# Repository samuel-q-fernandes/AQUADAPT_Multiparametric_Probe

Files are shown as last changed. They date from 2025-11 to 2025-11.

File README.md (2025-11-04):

# Development of a Cost-Effective Multiparametric Probe for Continuous, Real-Time Monitoring of Aquatic Environments

**AQUADAPT | AQUA-V1** is an open-source platform for in-situ water-quality/quantity monitoring (**pH, electrical conductivity (EC), temperature, and water level**). The system targets robust, long-term field deployments with an emphasis on reproducibility, traceability, and low total cost.

The hardware integrates an **ESP32** controller (LILYGO® T-Call with **SIM800L**) for data acquisition and processing, plus **GSM/GPRS** telemetry, **microSD** logging, and **solar power** support (MPPT + Li-ion). Firmware duty-cycles sensing and transmission, then enters **deep sleep** between cycles to minimize average power consumption, enabling multi-day autonomy and continuous operation under normal sunlight.

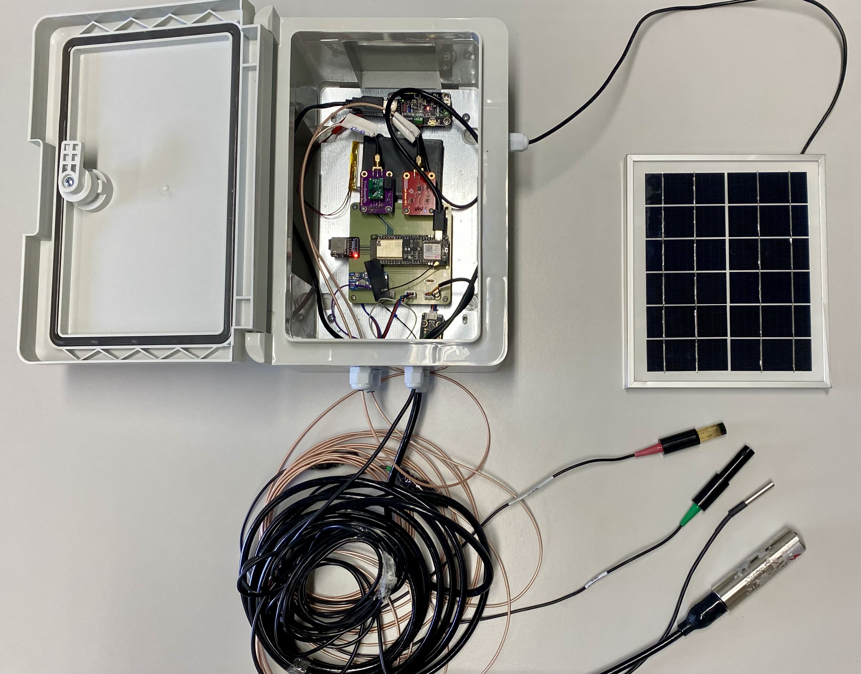
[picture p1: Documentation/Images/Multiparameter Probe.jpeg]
Multiparameter probe overview


This repository provides the full stack: **KiCad** design files, **Arduino/C++** firmware, a **PHP API** for authenticated data ingest, the **SQL schema** to bootstrap the database, and a **web dashboard** for data visualization. Documentation includes wiring, configuration, deployment notes, and server setup.

To support transparent metrology, the docs also detail the complete measurement workflow and a **GUM-conforming uncertainty budget** (expanded uncertainties reported at *k* = 2), making results auditable across deployments. A link to the peer-reviewed manuscript will be added here upon acceptance.

Software is released under the **MIT License** (see `LICENSE`). 
**A link to the peer-reviewed manuscript will be added here upon acceptance by the journal.**

## Bill of Materials (BOM)

*A summarized BOM based on the components described in the manuscript. 

> **Target cost:** sub-€1,000 (sensor/probe choices and enclosure options drive most of the variation).

| Subsystem | Item / Model | Qty | Notes |
|---|---|---:|---|
| **MCU, comms & logging** | **LILYGO® TTGO T-Call v1.4** (ESP32 + SIM800L) | 1 | ESP32 controller with integrated GSM/GPRS modem; UART to modem, SPI to microSD. |
|  | **microSD module + 16 GB microSD card** | 1 | On-device redundant logging (CSV/JSON). |
| **Analog / digital interfaces** | **EZO™ Isolator / isolated carrier (pH)** | 1 | Electrical isolation to reduce ground/EMI coupling into pH front-end. |
|  | **EZO™ Conductivity (EC) Circuit** | 1 | Digital EC interface (I²C/UART); temperature aware as configured. |
|  | **MT3608 DC–DC boost converter** | 1 | Boost supply (e.g., 5 V → 12–36 V) for the level/pressure sensor. |
| **Sensors** | **Mini Lab-grade pH probe (ENV-20-pH)** | 1 | Glass electrode; used with Nernst temperature compensation. |
|  | **Mini Conductivity probe K = 1.0 (ENV-20-EC-K1.0)** | 1 | EC probe; three-point calibration via cell constant. |
|  | **DS18B20 temperature sensor** | 1 | 12-bit (0.0625 °C); OneWire; **4.7 kΩ** pull-up to Vcc. |
|  | **Industrial submersible pressure/level sensor (0–5 m)** | 1 | Analog output; hydrostatic level; powered via MT3608 boost. |
| **Custom PCB** | **Main carrier PCB (≈100 × 100 mm)** | 1 | Breakouts and headers for pH/EC/level/DS18B20, modem, power rails, and microSD. |
| **Power** | **PV panel (≈6 V / 5 W)** | 1 | Solar charging for autonomous operation. |
|  | **MPPT charge/power manager (≈900 mA charge)** | 1 | Manages PV → Li-ion charging and system power. |
|  | **Li-ion battery (3.7 V, ~4000 mAh)** | 1 | Energy storage; supports multi-day duty cycle. |
| **Cabling & enclosure** | **IP-rated enclosure with cable glands** | 1 | Houses electronics; strain relief and desiccant recommended. |
|  | **Sensor cable harness (~7 m)** | 2 | Extends probes from housing to water column. |
| **Passives** | **4.7 kΩ resistor** | 1 | DS18B20 pull-up. |
|  | **Sense resistor ~120 Ω (level channel)** | 1 | Per level/pressure readout design. |
| **Calibration materials** | **pH buffers (e.g., pH 4, 7, 9, 10; traceable)** | set | Used for multi-point pH calibration at measurement temperature. |
|  | **EC standards (e.g., 1413, 12 880, 80 000 µS/cm)** | set | Used to estimate cell constant and verify linearity. |

### Sourcing and integration notes
- **Region & connectivity:** confirm 2G/GPRS availability; if unavailable, substitute LTE-M/NB-IoT modem with matching firmware and power profile.  
- **Power budget:** size PV and battery for sampling + telemetry duty cycle and local insolation; include winter/cloud margins.  
- **EMI & grounding:** keep high-impedance pH paths short and away from digital lines; consider shielded cables and star-grounding.  
- **Calibration traceability:** document buffer/standard lot numbers, temperatures, and dates; store calibration IDs in firmware/config.

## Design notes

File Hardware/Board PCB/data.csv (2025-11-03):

Date | Temperature (°C) | Level (m) | Battery (bit) | Battery (%) | pH | Conductivity (uS/cm)
2023-02-27T12:04:39 | 18.00 | 64.59 | 5030 | 100.00 | 7.55 | 272.70
2023-02-27T12:05:02 | 18.00 | 63.93 | 5030 | 100.00 | 7.55 | 272.90
2023-02-27T12:05:34 | 18.00 | 57.30 | 5028 | 100.00 | 7.55 | 274.00
2023-02-27T12:08:57 | 18.06 | 58.46 | 5042 | 100.00 | 7.56 | 275.40
2023-02-27T12:09:22 | 18.12 | 52.79 | 5024 | 100.00 | 7.60 | 275.80
2023-02-27T12:11:48 | 18.12 | 65.50 | 5024 | 100.00 | 7.58 | 274.80
2023-02-27T12:14:06 | 18.19 | 55.31 | 5024 | 100.00 | 7.61 | 276.60
2023-02-27T12:16:24 | 18.31 | 54.86 | 5030 | 100.00 | 7.56 | 277.30
2023-02-27T12:18:41 | 18.37 | 57.76 | 5024 | 100.00 | 7.57 | 276.20
2023-02-27T12:20:57 | 18.44 | 66.08 | 5022 | 100.00 | 7.57 | 278.60
2023-02-27T12:23:26 | 18.56 | 65.46 | 5024 | 100.00 | 7.13 | 190.90

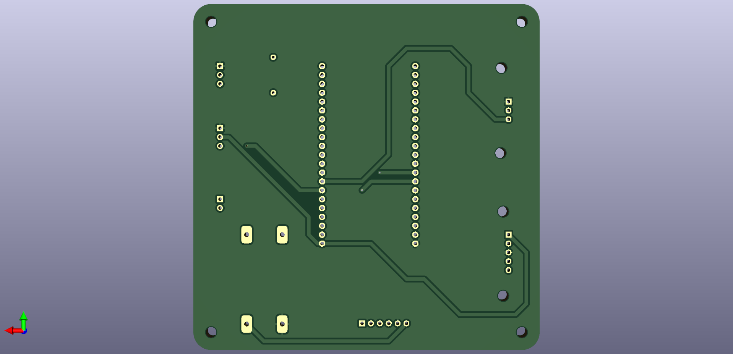
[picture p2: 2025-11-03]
Hardware/Board PCB/Board V1.0_bottom.png

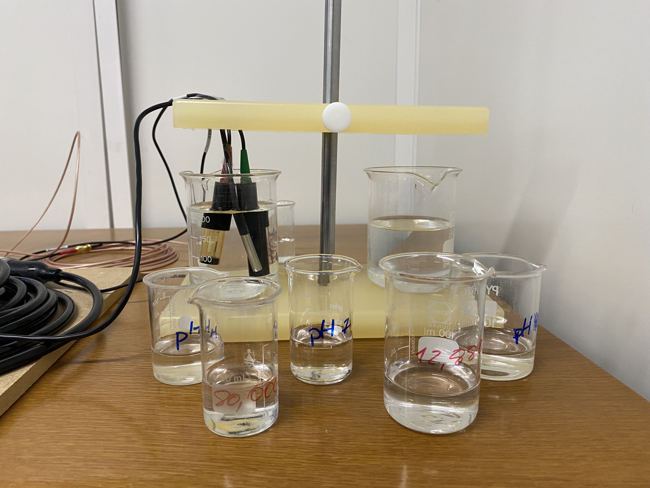
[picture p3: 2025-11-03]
Hardware/Board PCB/Sensores.jpeg

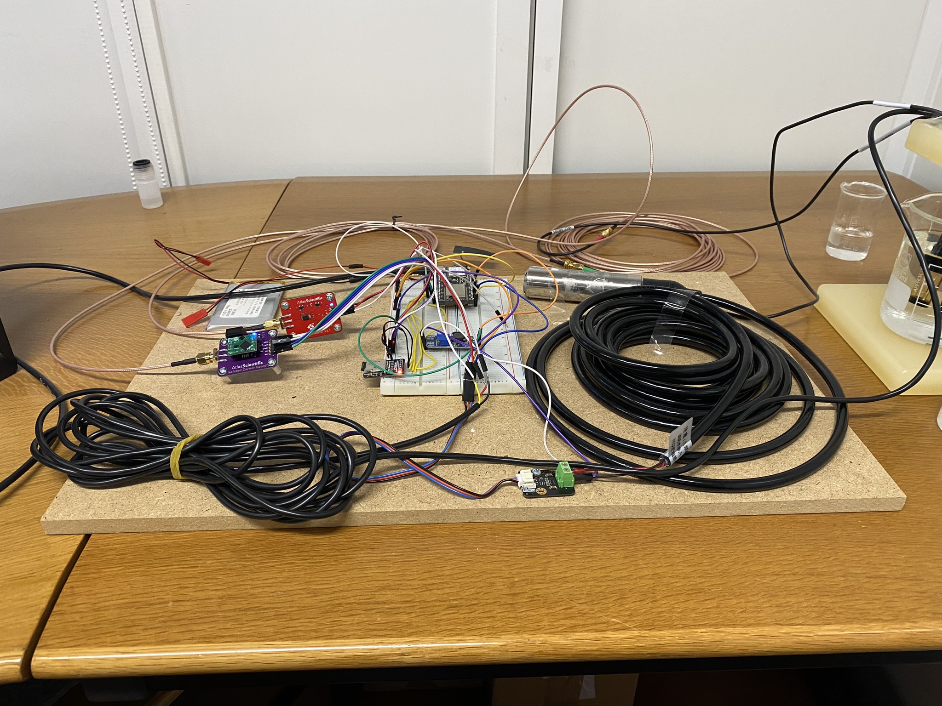
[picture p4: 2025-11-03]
Hardware/Board PCB/Sonda MP_.jpeg

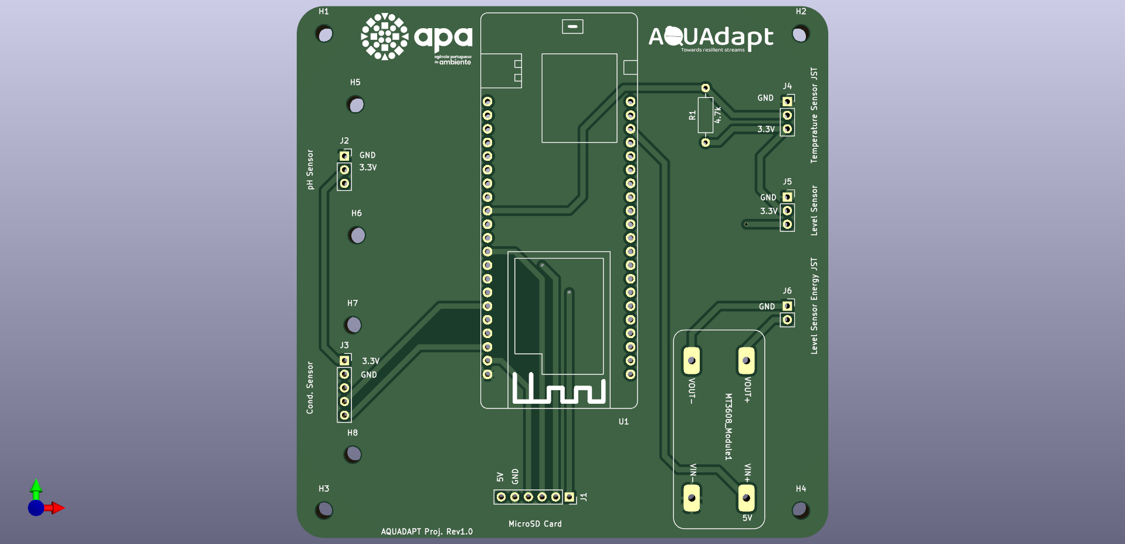
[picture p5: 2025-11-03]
Hardware/Board PCB/Board V1.0/Board V1.0_front.png

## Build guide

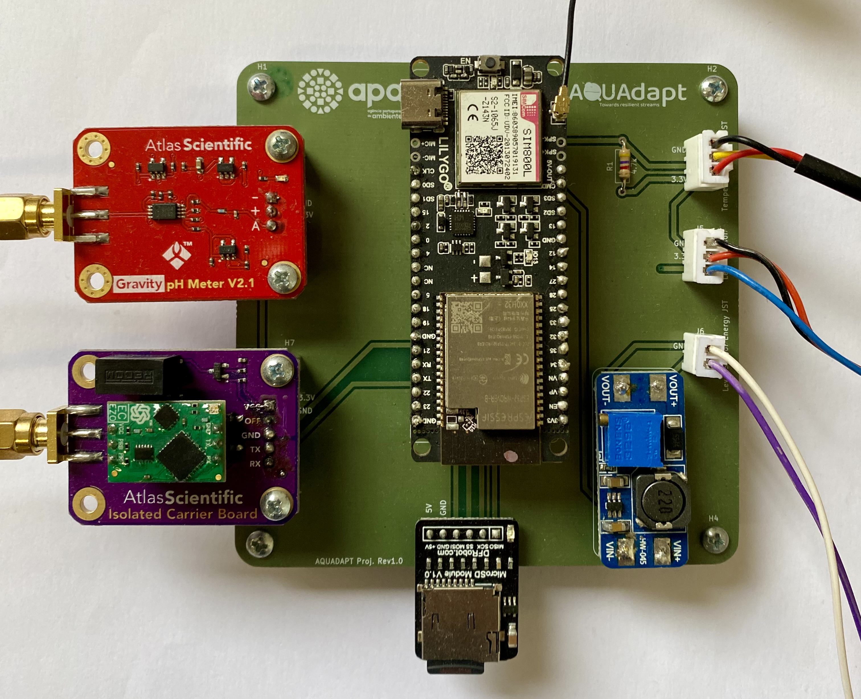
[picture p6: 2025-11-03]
Documentation/Images/Board Assembled 2.jpeg

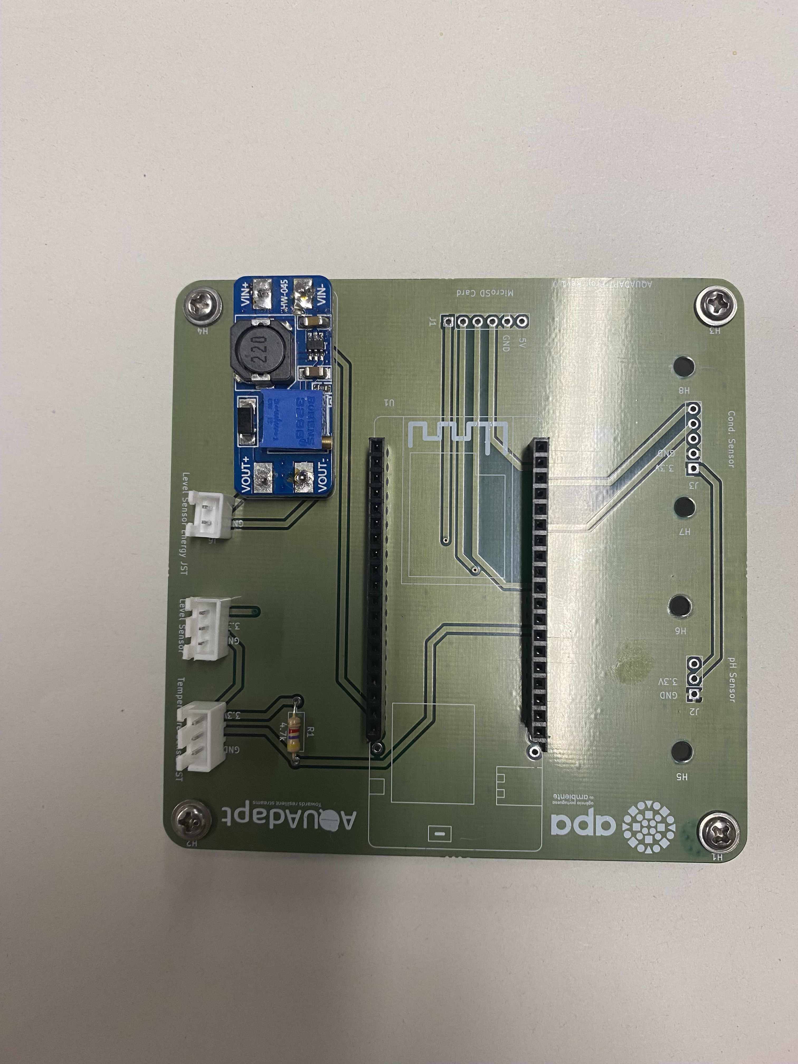
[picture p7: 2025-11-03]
Documentation/Images/Board Proto Step Up.jpeg

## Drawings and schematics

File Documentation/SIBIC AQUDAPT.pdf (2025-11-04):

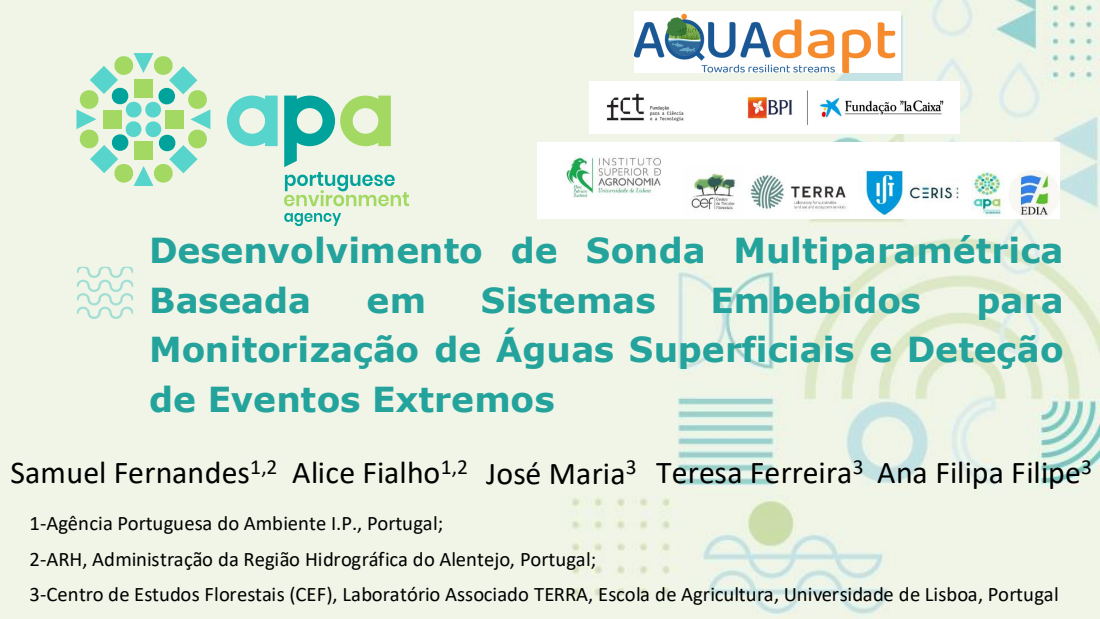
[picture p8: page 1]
Baseada; Sistemas; Embebidos; para; Samuel Fernandes¹,2 Alice Fialho¹,2; Teresa Ferreira³ Ana Filipa Filipe³; José Maria³

Desenvolvimento de Sonda Multiparamétrica
Monitorização de Águas Superficiais e Deteção
de Eventos Extremos

1-Agência Portuguesa do Ambiente I.P., Portugal;
2-ARH, Administração da Região Hidrográfica do Alentejo, Portugal;
3-Centro de Estudos Florestais (CEF), Laboratório Associado TERRA, Escola de Agricultura, Universidade de Lisboa, Portugal

## CONTENTS

## 1. Introdução

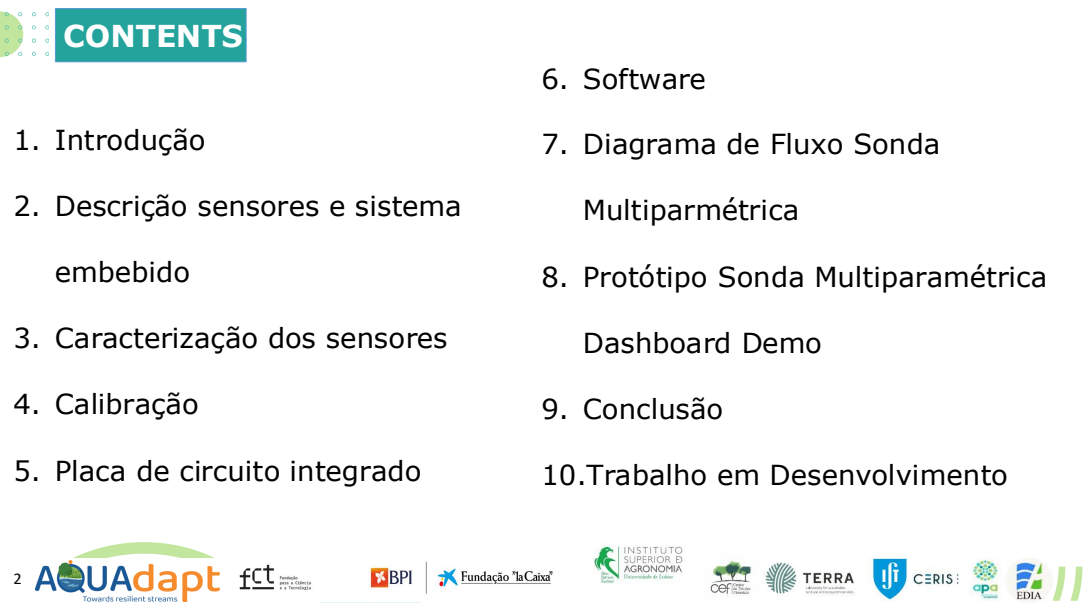
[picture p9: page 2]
embebido; 4. Calibração; 6. Software; Multiparmétrica; Dashboard Demo; 9. Conclusão

7. Diagrama de Fluxo Sonda

2. Descrição sensores e sistema

8. Protótipo Sonda Multiparamétrica

3. Caracterização dos sensores

5. Placa de circuito integrado

10.Trabalho em Desenvolvimento

## 1. Introdução

## A monitorização contínua em tempo real dos parâmetros de quantidade e qualidade da

## água é essencial para a deteção de eventos de poluição, tomada de decisão e gestão

eficaz de recursos naturais.

## Tradicionalmente a avaliação da qualidade da água é realizada por meio de amostragem direta e em laboratórios

## Não permite monitorização contínua nem observação de tendências sazonais

## Exigem custos significativos e podem estar sujeitas a potenciais degradações das amostras, erros de transcrição e atrasos temporais

## 1. Introdução

## O principal objetivo deste estudo é desenvolver uma sonda multiparamétrica com envio de dados remoto para a avaliação da qualidade e quantidade da água, visando melhorar a

precisão dos dados e apoiar a tomada de decisões na gestão de recursos hídricos.

## Os objetivos específicos são:

## - Determinar a incerteza associada aos sensores de pH, nível de água e

## condutividade

## - Realizar uma calibração dos sensores de pH, condutividade e nível de água

## - Projetar e desenvolver uma placa de circuito impresso para a integração dos

## componentes

## 2. Sensor pH

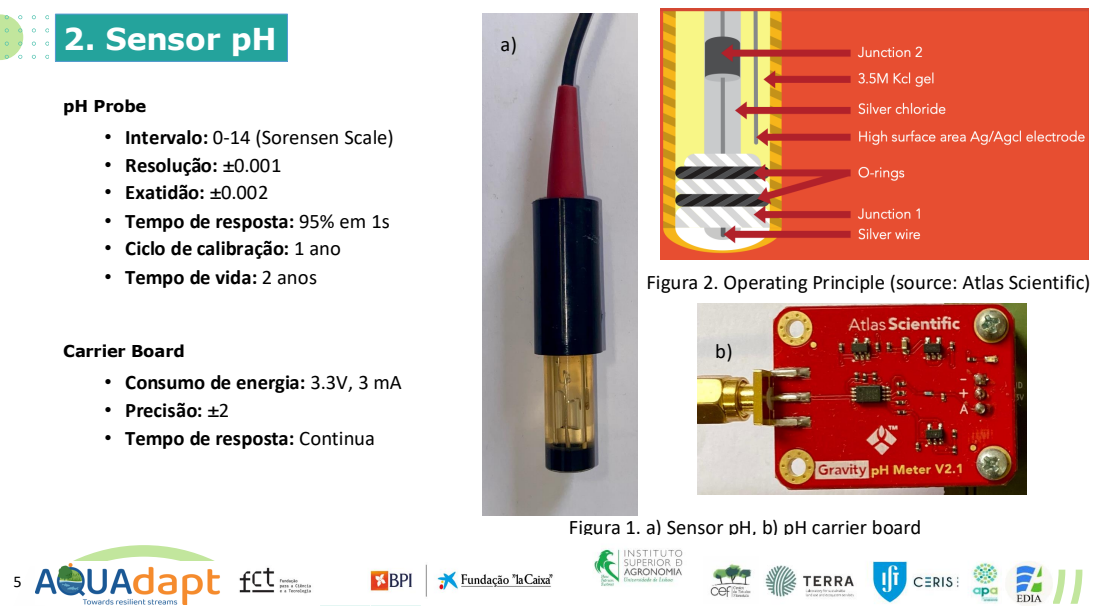
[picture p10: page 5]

pH Probe
• Intervalo: 0-14 (Sorensen Scale)
• Resolução: ±0.001
• Exatidão: ±0.002
• Tempo de resposta: 95% em 1s
• Ciclo de calibração: 1 ano
• Tempo de vida: 2 anos

Figura 2. Operating Principle (source: Atlas Scientific)

Carrier Board
• Consumo de energia: 3.3V, 3 mA
• Precisão: ±2
• Tempo de resposta: Continua

Figura 1. a) Sensor pH, b) pH carrier board

## 2. Sensor Condutividade

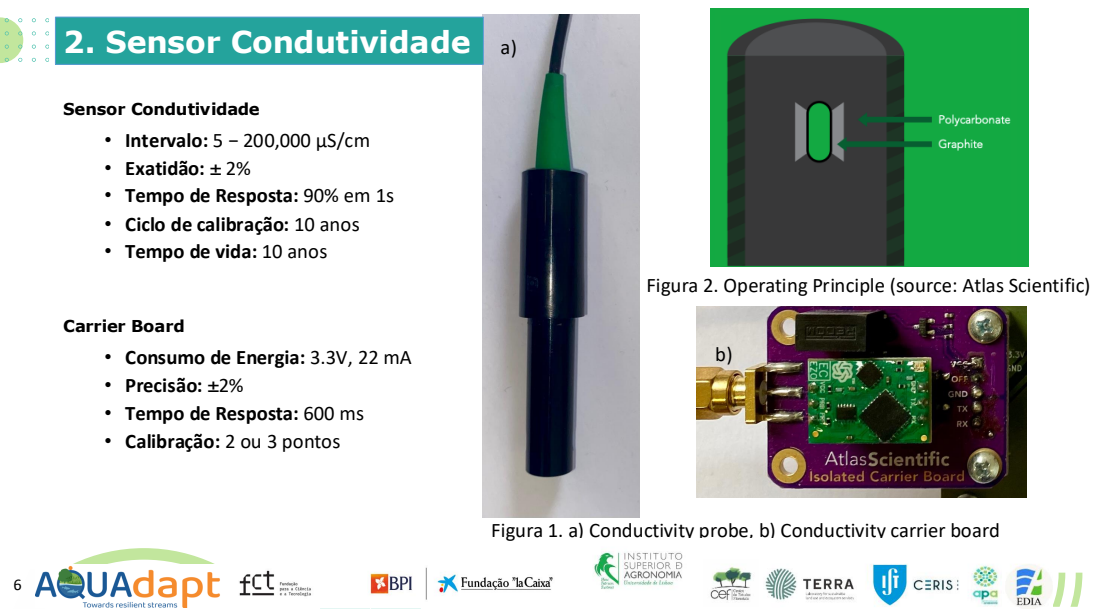
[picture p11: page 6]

Sensor Condutividade
• Intervalo: 5 − 200,000 μS/cm
• Exatidão: ± 2%
• Tempo de Resposta: 90% em 1s
• Ciclo de calibração: 10 anos
• Tempo de vida: 10 anos

Figura 2. Operating Principle (source: Atlas Scientific)

Carrier Board
• Consumo de Energia: 3.3V, 22 mA
• Precisão: ±2%
• Tempo de Resposta: 600 ms
• Calibração: 2 ou 3 pontos

Figura 1. a) Conductivity probe, b) Conductivity carrier board

## 2. Water Level Sensor

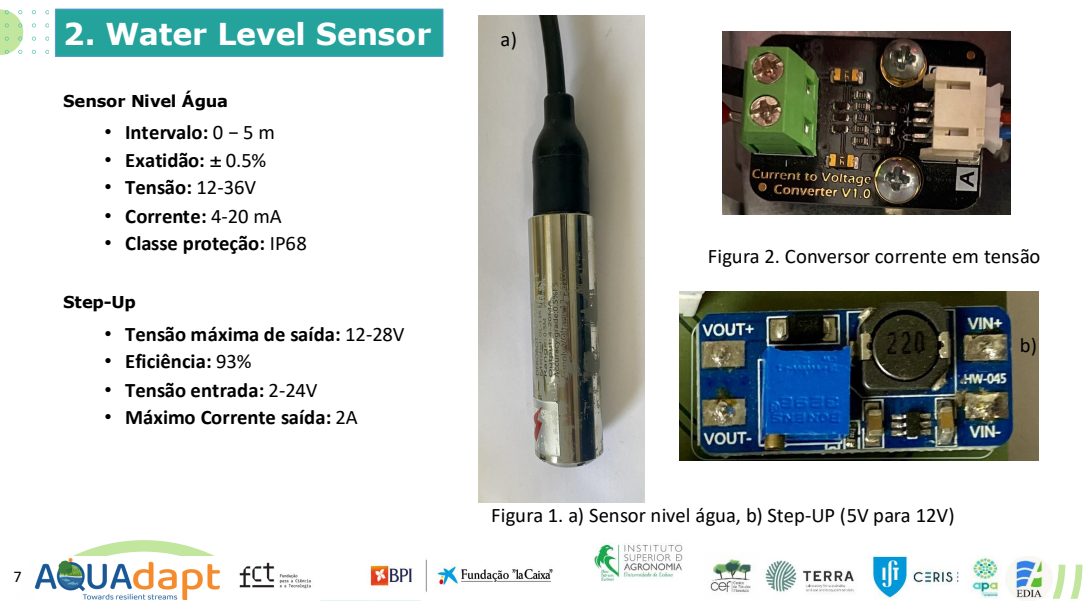
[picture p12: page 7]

Sensor Nivel Água
• Intervalo: 0 − 5 m
• Exatidão: ± 0.5%
• Tensão: 12-36V
• Corrente: 4-20 mA
• Classe proteção: IP68

Figura 2. Conversor corrente em tensão

Step-Up
• Tensão máxima de saída: 12-28V
• Eficiência: 93%
• Tensão entrada: 2-24V
• Máximo Corrente saída: 2A

Figura 1. a) Sensor nivel água, b) Step-UP (5V para 12V)

## 2. Temperature Sensor

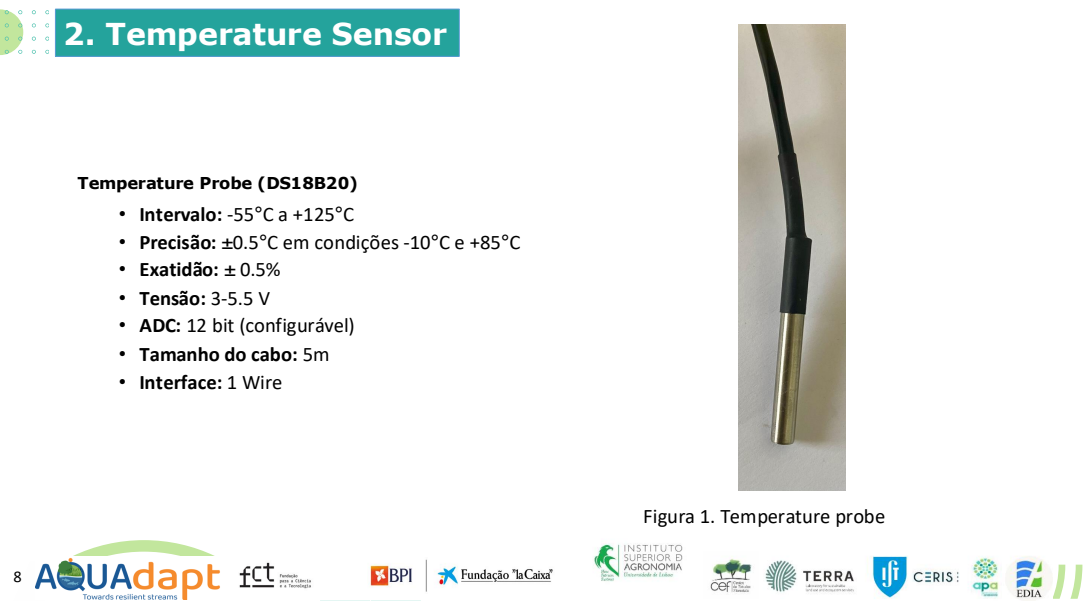
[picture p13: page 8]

Temperature Probe (DS18B20)
• Intervalo: -55°C a +125°C
• Precisão: ±0.5°C em condições -10°C e +85°C
• Exatidão: ± 0.5%
• Tensão: 3-5.5 V
• ADC: 12 bit (configurável)
• Tamanho do cabo: 5m
• Interface: 1 Wire

Figura 1. Temperature probe

## 2. Sistema Embebido

Lilygo SIM800L T-Call V1.4

- Microcontrolador baseado em um ESP32 (módulo WROVER, processador dual-core de 240 MHz)
- Possui um módulo SIM800L GSM/GPRS integrado para comunicação de longa distância
- Apresenta uma conexão para cartão nano SIM
- Integra uma funcionalidade de deep-sleep, que permite colocar a placa em modo de baixo consumo de energia entre as medições
- Tensão: 5V DC (via USB-C) of 3.3V DC (via 3V3 pin)
- ADC: Two ACD channels with 12 bit resolution
- Protocolos de Comunicação: SPI, I2C, CAN, and LIN, and UART
- Memória Flash: 4MB
- GPIO tensão: 3.3V*

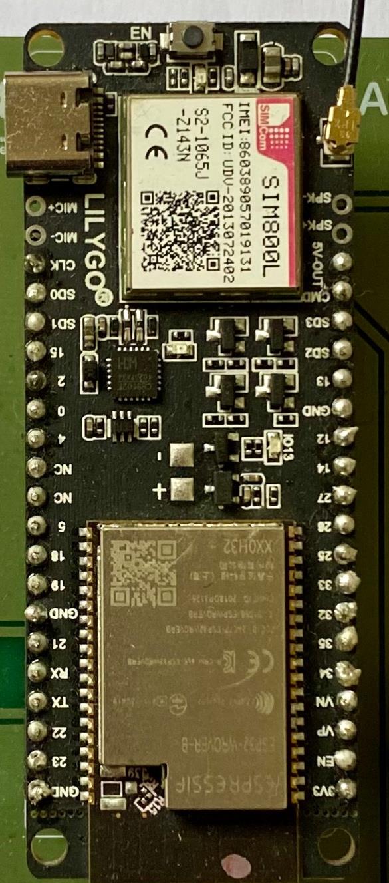
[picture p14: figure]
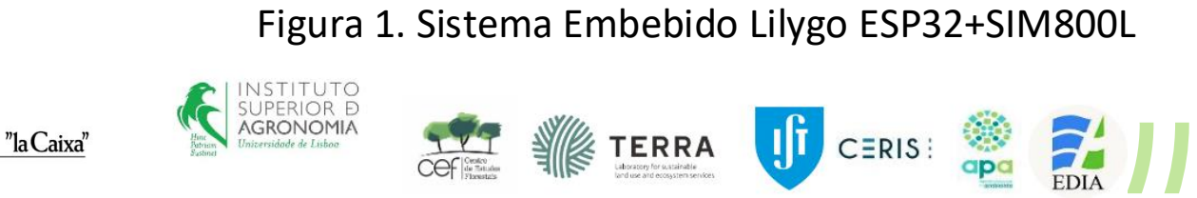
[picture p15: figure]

Figura 1. Sistema Embebido Lilygo ESP32+SIM800L
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

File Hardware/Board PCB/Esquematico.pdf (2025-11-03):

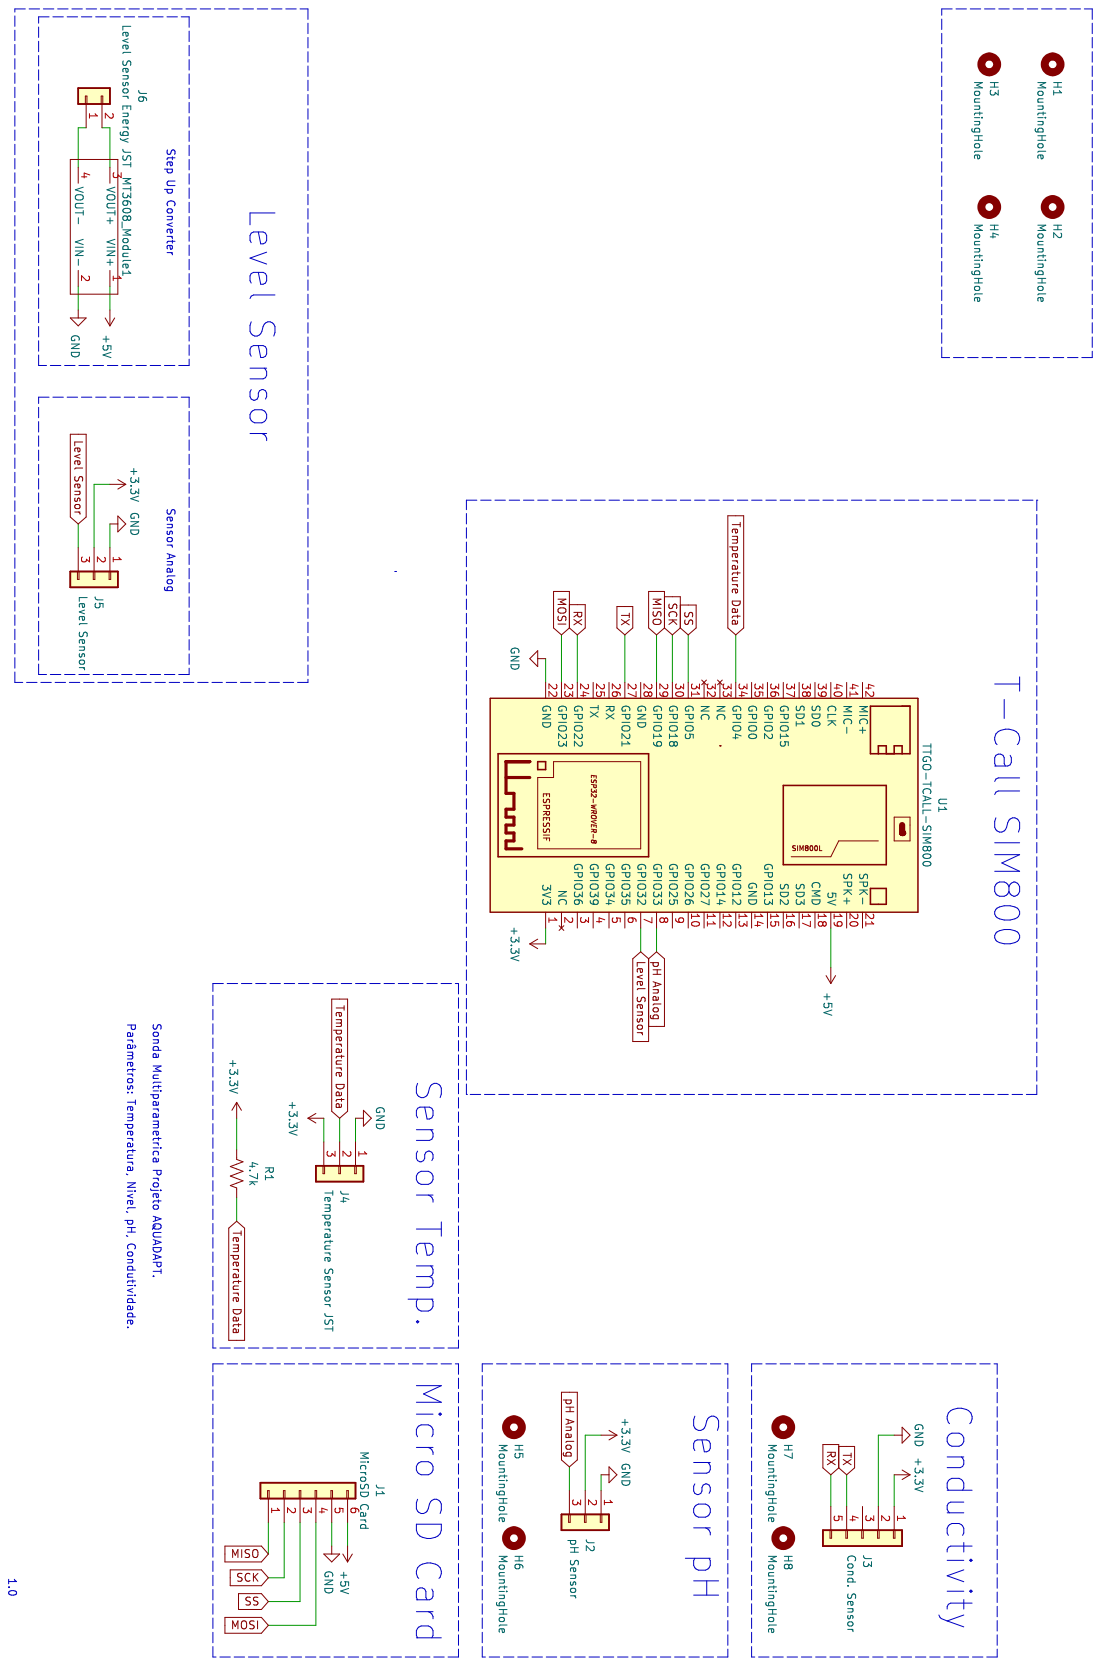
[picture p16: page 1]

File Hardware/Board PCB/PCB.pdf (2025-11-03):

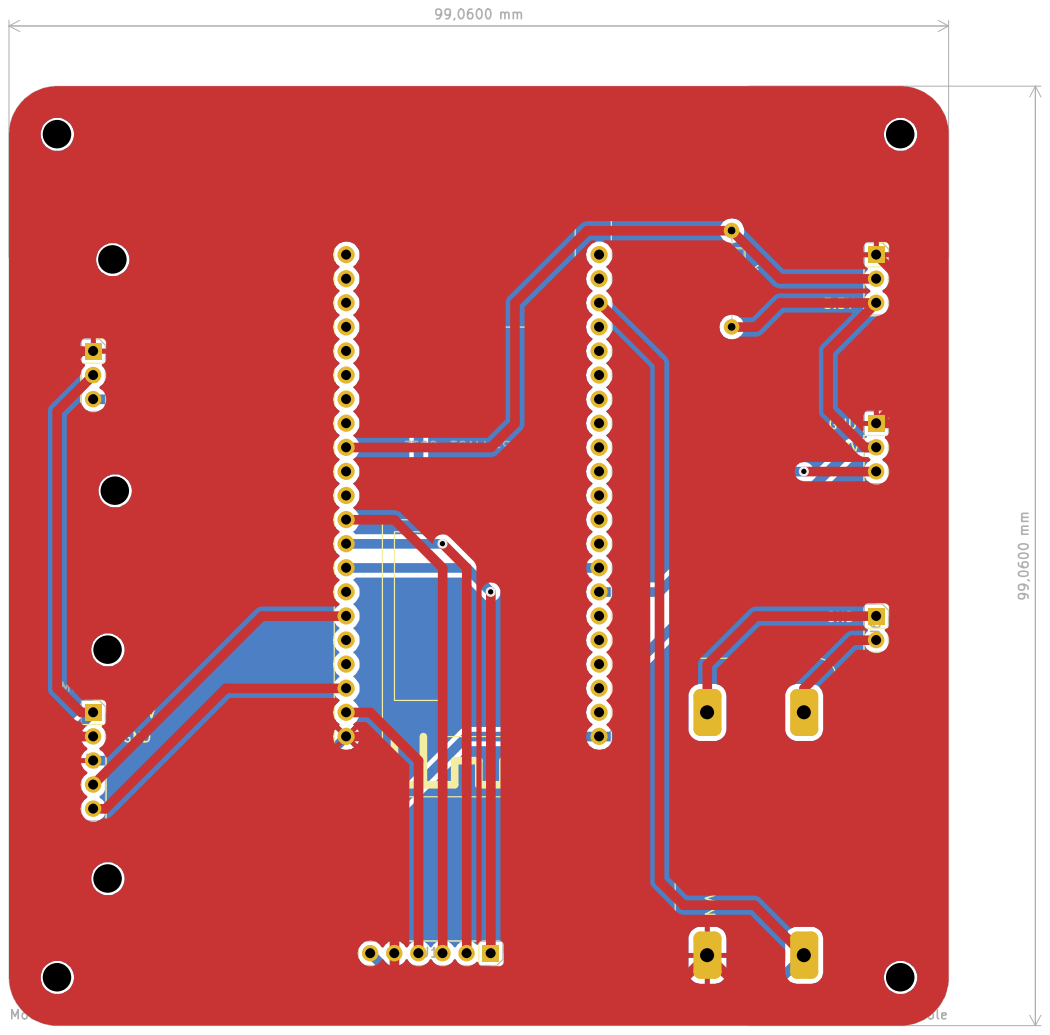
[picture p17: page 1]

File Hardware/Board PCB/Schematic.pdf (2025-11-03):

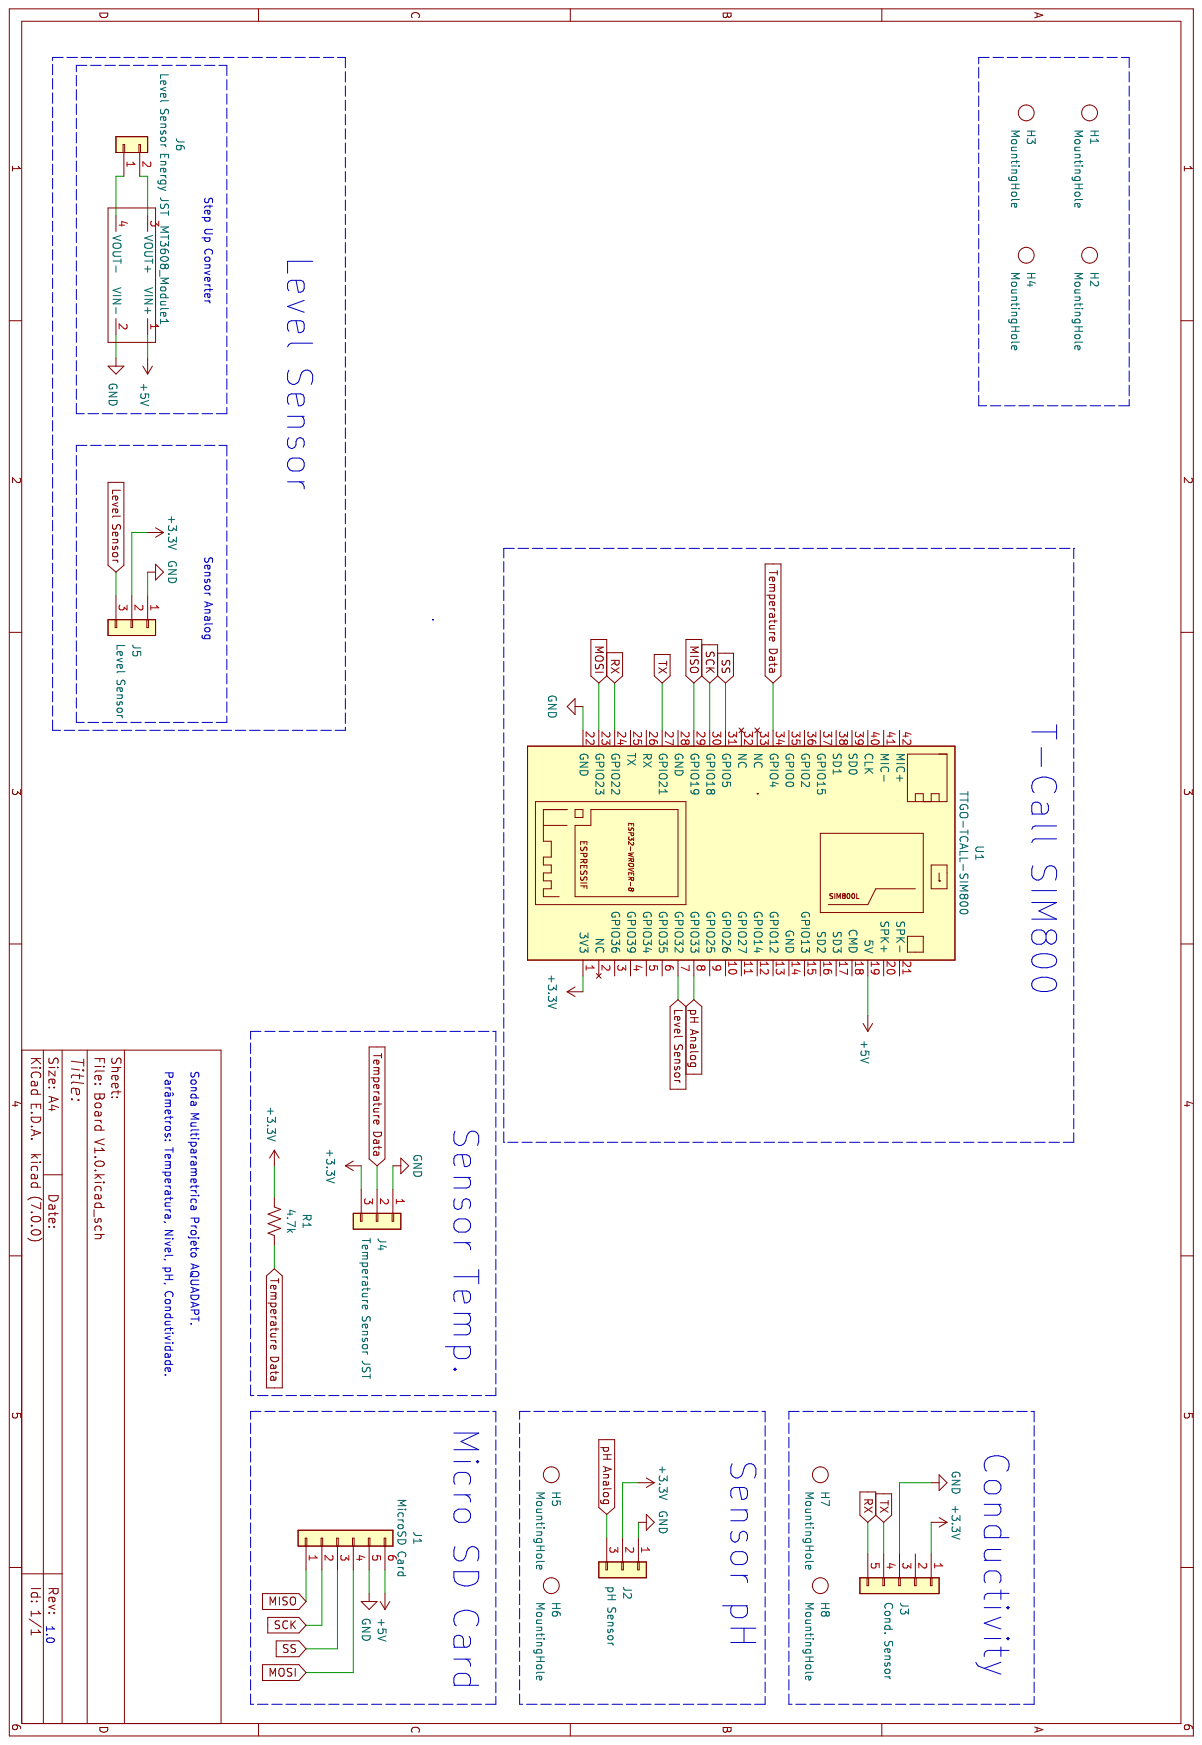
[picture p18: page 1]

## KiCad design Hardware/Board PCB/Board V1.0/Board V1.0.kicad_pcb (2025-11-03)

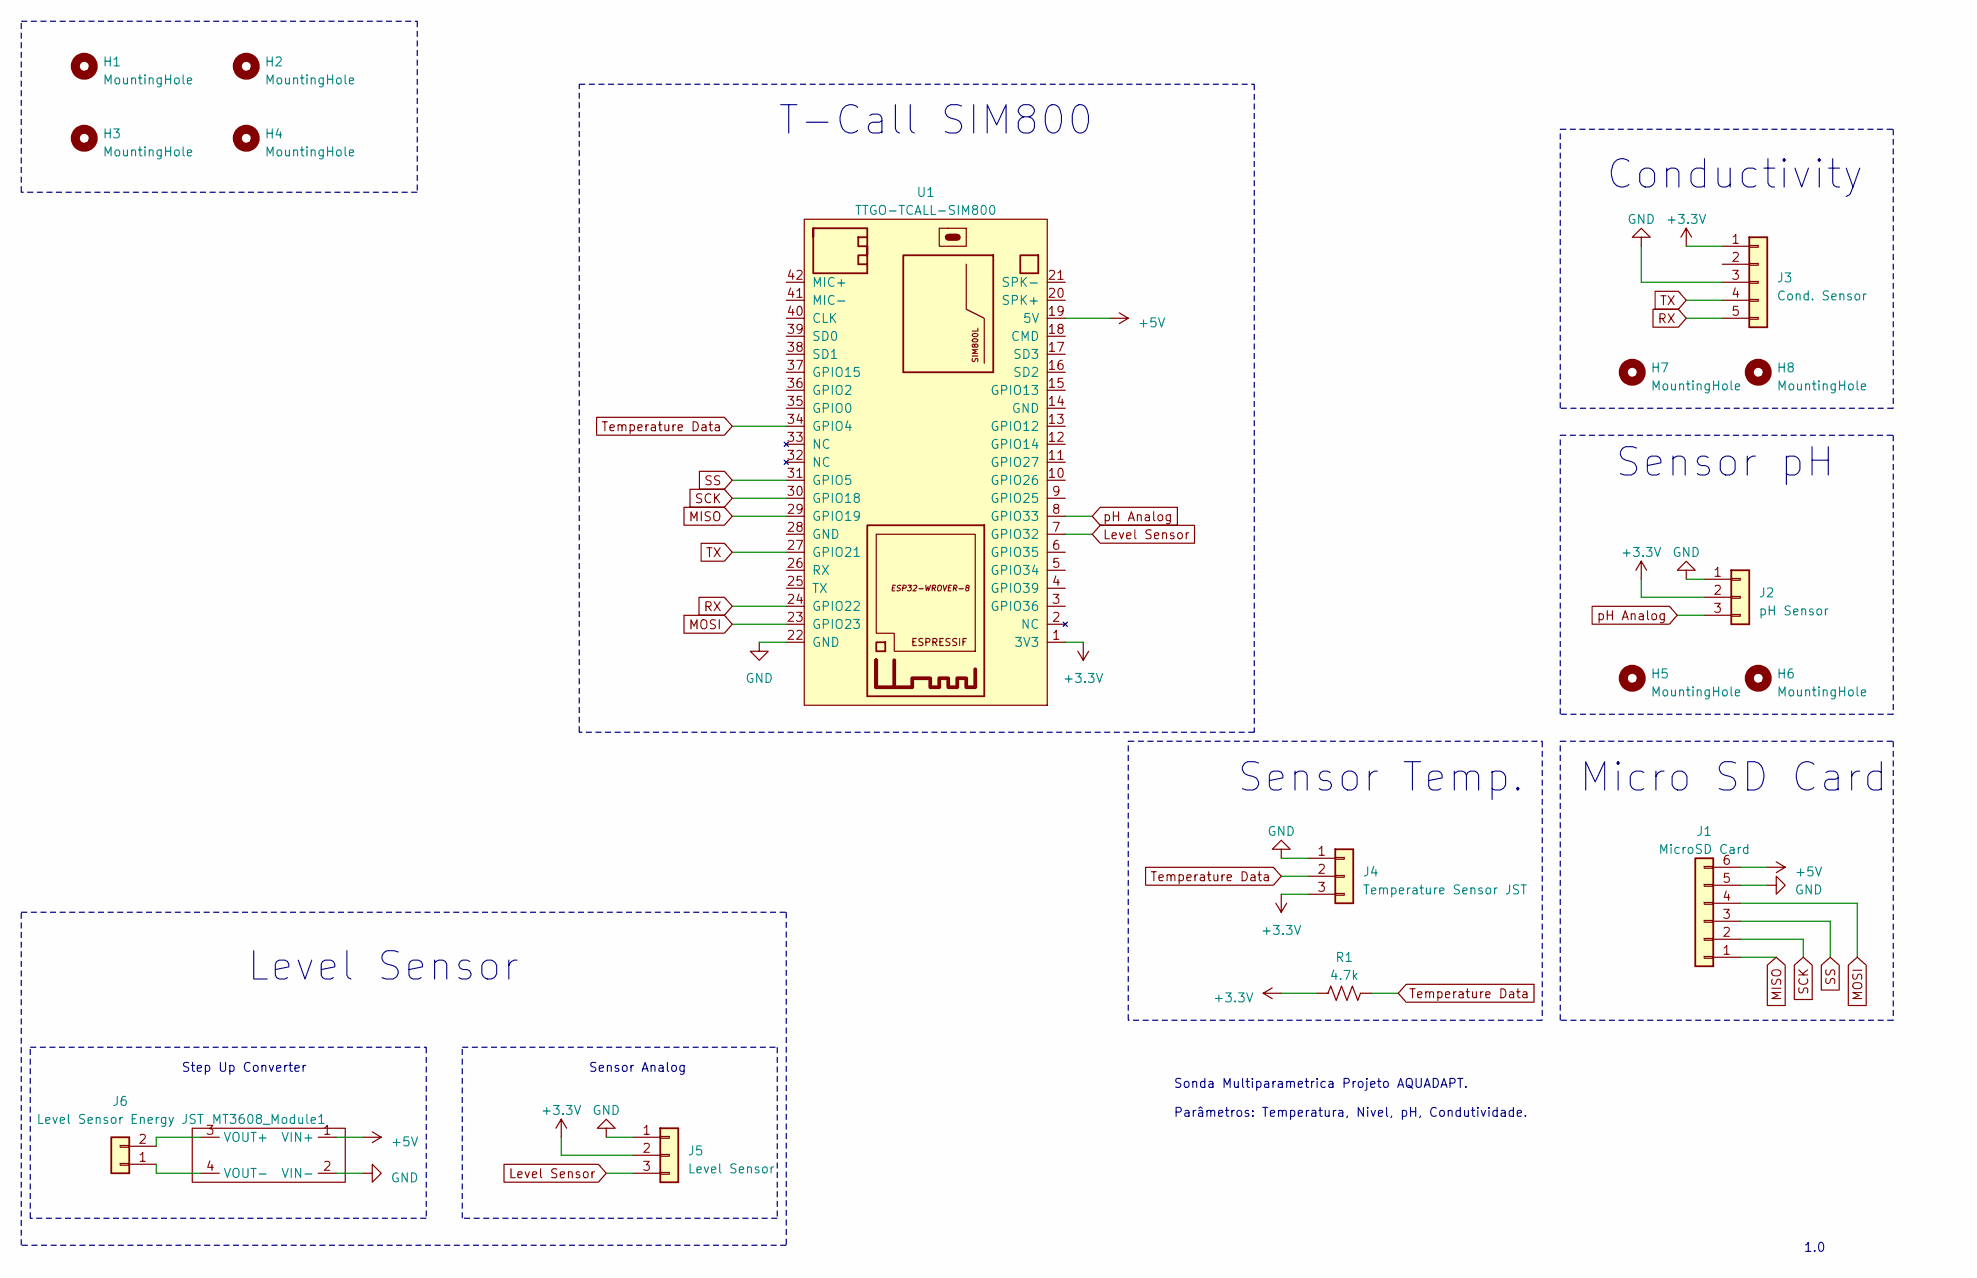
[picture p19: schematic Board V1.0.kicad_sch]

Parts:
H1, H2, H3, H4, H5, H6, H7, H8: MountingHole; MountingHole_3mm
J1: MicroSD Card; PinSocket_1x06_P2.54mm_Vertical
J2: pH Sensor; PinSocket_1x03_P2.54mm_Vertical
J3: Cond. Sensor; PinSocket_1x05_P2.54mm_Vertical
J4: Temperature Sensor JST; PinSocket_1x03_P2.54mm_Vertical
J5: Level Sensor; PinSocket_1x03_P2.54mm_Vertical
J6: Level Sensor Energy JST; PinSocket_1x02_P2.54mm_Vertical
MT3608_Module1: MT3608-Module
R1: 4.7k; R_Axial_DIN0207_L6.3mm_D2.5mm_P10.16mm_Horizontal
U1: TTGO-TCALL-SIM800

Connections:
+3.3V: J2.2, J3.1, J4.3, J5.2, R1.1, U1.1 (3V3)
+5V: J1.6, MT3608_Module1.1 (VIN+), U1.19 (5V)
GND: J1.5, J2.1, J3.3, J4.1, J5.1, MT3608_Module1.2 (VIN-), U1.22 (GND)
Level Sensor: J5.3, U1.7 (GPIO32)
MISO: J1.1, U1.29 (GPIO19)
MOSI: J1.4, U1.23 (GPIO23)
unnamed: J6.1, MT3608_Module1.4 (VOUT-)
unnamed: J6.2, MT3608_Module1.3 (VOUT+)
RX: J3.5, U1.24 (GPIO22)
SCK: J1.2, U1.30 (GPIO18)
SS: J1.3, U1.31 (GPIO5)
TX: J3.4, U1.27 (GPIO21)
Temperature Data: J4.2, R1.2, U1.34 (GPIO4)
pH Analog: J2.3, U1.8 (GPIO33)

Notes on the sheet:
Sensor Temp.
Step Up Converter
Conductivity
Sonda Multiparametrica Projeto AQUADAPT. Parâmetros: Temperatura, Nivel, pH, Condutividade.
T-Call SIM800
Sensor Analog
1.0
Sensor pH
Level Sensor
Micro SD Card

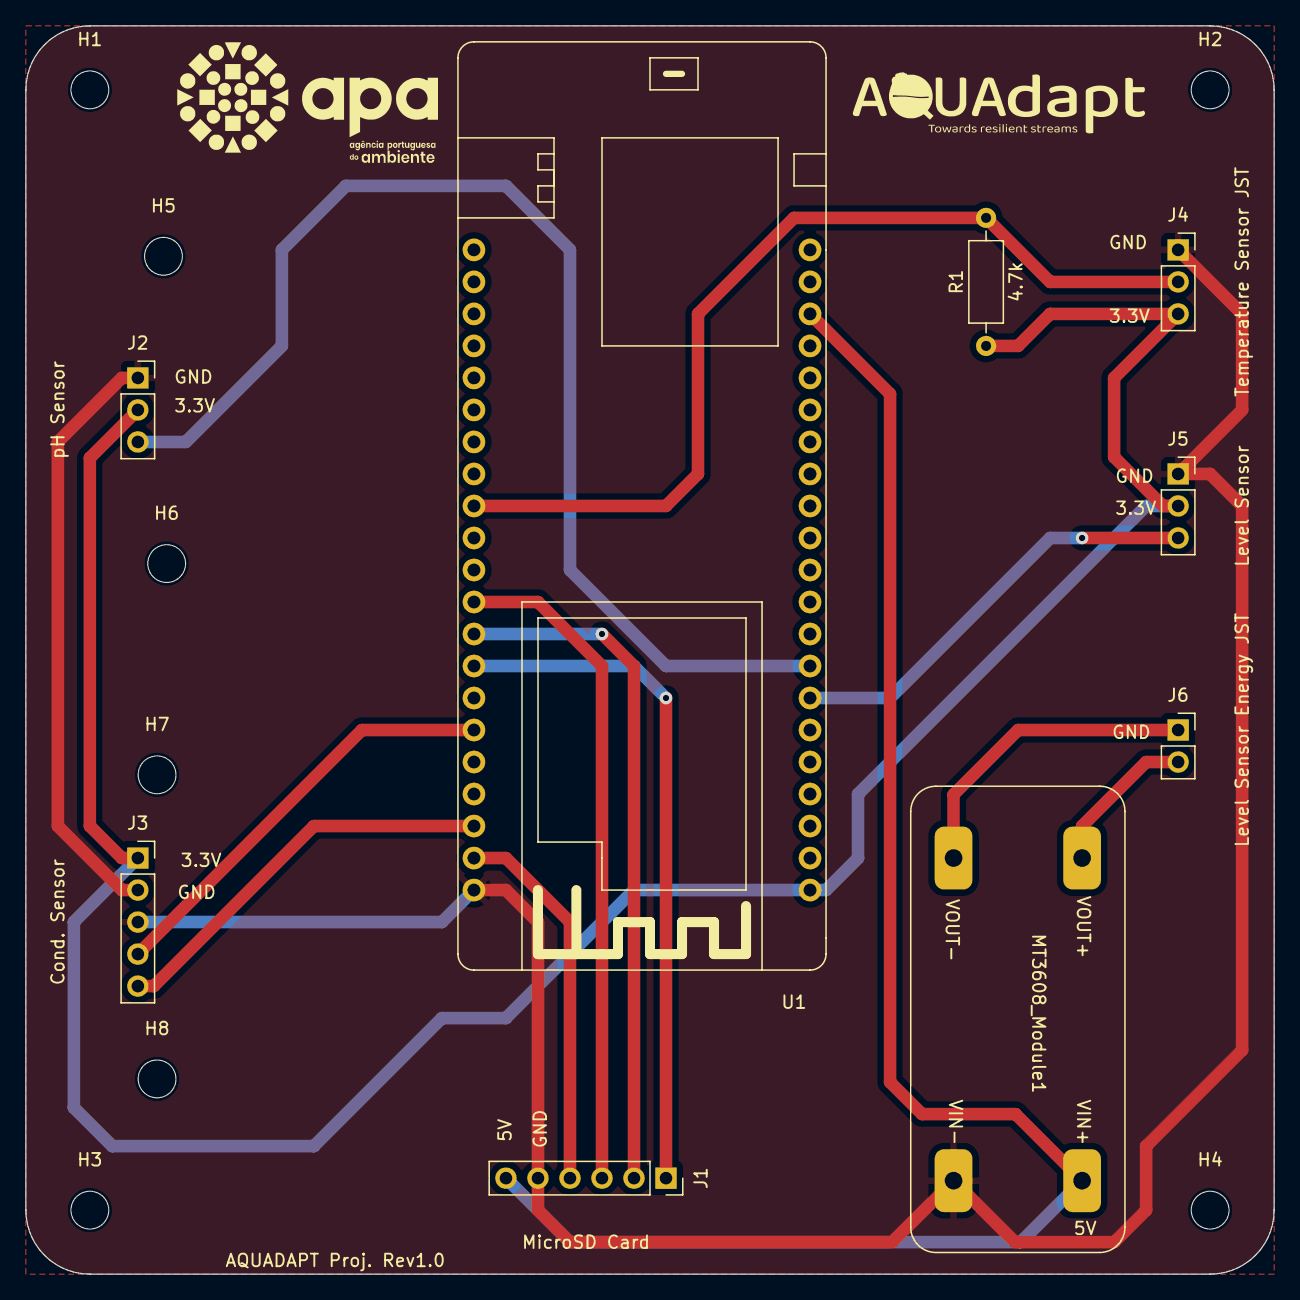
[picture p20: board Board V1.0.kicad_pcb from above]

Board: 2 copper layers, 99.1 x 99.1 mm, 17 parts (0 on the bottom side), 14 nets.

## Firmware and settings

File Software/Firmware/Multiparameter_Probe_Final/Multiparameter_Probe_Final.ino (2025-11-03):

#include <OneWire.h>
#include <Wire.h>
#include <DallasTemperature.h>
//#include <WiFi.h>
//#include <WiFiMulti.h>
//#include <HTTPClient.h>
#include <FirebaseESP32.h>
//Provide the token generation process info.
#include "addons/TokenHelper.h"
//Provide the RTDB payload printing info and other helper functions.
#include "addons/RTDBHelper.h"

#include <driver/adc.h>
#include <esp_adc_cal.h>

#define ADC_PIN ADC1_CHANNEL_7  // Use GPIO36 (ADC1_CHANNEL_0) or another ADC pin

esp_adc_cal_characteristics_t *adc_chars;  // Declare adc_chars globally

// Your GPRS credentials (leave empty, if not needed)
const char apn[] = "";  // APN (example: internet.vodafone.pt) use https://wiki.apnchanger.org
const char gprsUser[] = "";             // GPRS User
const char gprsPass[] = "";             // GPRS Password

// SIM card PIN (leave empty, if not defined)
const char simPIN[] = "";
//const char simPIN[]   = "";

// Server details
// The server variable can be just a domain name or it can have a subdomain. It depends on the service you are using
const char server[] = "";                // domain name: example.com, maker.ifttt.com, etc
const char resource[] = "";  // resource path, for example: /post-data.php
const int port = 80;                                    // server port number



// Keep this API Key value to be compatible with the PHP code provided in the project page.
// If you change the apiKeyValue value, the PHP file /post-data.php also needs to have the same key
String apiKeyValue = "";

String idName = "AQUA_V1";

// TTGO T-Call pins
#define MODEM_RST 5
#define MODEM_PWKEY 4
#define MODEM_POWER_ON 23
#define MODEM_TX 27
#define MODEM_RX 26
#define I2C_SDA 21
#define I2C_SCL 22
// BME280 pins
#define I2C_SDA_2 18
#define I2C_SCL_2 19

// Set serial for debug console (to Serial Monitor, default speed 115200)
#define SerialMon Serial
// Set serial for AT commands (to SIM800 module)
#define SerialAT Serial1

// Configure TinyGSM library
#define TINY_GSM_MODEM_SIM800    // Modem is SIM800
#define TINY_GSM_RX_BUFFER 1024  // Set RX buffer to 1Kb

// Define the serial console for debug prints, if needed
//#define DUMP_AT_COMMANDS

#include <TinyGsmClient.h>

#ifdef DUMP_AT_COMMANDS
#include <StreamDebugger.h>
StreamDebugger debugger(SerialAT, SerialMon);
TinyGsm modem(debugger);
#else
TinyGsm modem(SerialAT);
#endif



// I2C for SIM800 (to keep it running when powered from battery)
TwoWire I2CPower = TwoWire(0);



// TinyGSM Client for Internet connection
TinyGsmClient client(modem);

#define uS_TO_S_FACTOR 1000000UL /* Conversion factor for micro seconds to seconds */
#define TIME_TO_SLEEP 3600       /* Time ESP32 will go to sleep (in seconds) 3600 seconds = 1 hour */

#define IP5306_ADDR 0x75
#define IP5306_REG_SYS_CTL0 0x00

bool setPowerBoostKeepOn(int en) {
  I2CPower.beginTransmission(IP5306_ADDR);
  I2CPower.write(IP5306_REG_SYS_CTL0);
  if (en) {
    I2CPower.write(0x37);  // Set bit1: 1 enable 0 disable boost keep on
  } else {
    I2CPower.write(0x35);  // 0x37 is default reg value
  }
  return I2CPower.endTransmission() == 0;
}

#include "FS.h"
#include "SD.h"
#include "SPI.h"
//#include <WiFiClientSecure.h>

//Parametros cartao SD
#define SCK 18
#define MISO 19
#define MOSI 23
#define CS 5

SPIClass spi = SPIClass(VSPI);

// Variaveis sensor de pH
// #define USE_PULSE_OUT

#ifdef USE_PULSE_OUT
#include "ph_iso_grav.h"
Gravity_pH_Isolated pH = Gravity_pH_Isolated(33);
#else
#include "ph_grav.h"
Gravity_pH pH = Gravity_pH(33);
#endif

uint8_t user_bytes_received = 0;
const uint8_t bufferlen = 32;
char user_data[bufferlen];

//Variaveis sensor condutividade

#define address 100  //default I2C ID number for EZO EC Circuit.

char computerdata[32];            //we make a 32 byte character array to hold incoming data from a pc/mac/other.
byte received_from_computer = 0;  //we need to know how many characters have been received.
byte serial_event = 0;            //a flag to signal when data has been received from the pc/mac/other.
byte code = 0;                    //used to hold the I2C response code.
char ec_data[32];                 //we make a 32 byte character array to hold incoming data from the EC circuit.
byte in_char = 0;                 //used as a 1 byte buffer to store inbound bytes from the EC Circuit.
byte i = 0;                       //counter used for ec_data array.
int time_ = 570;                  //used to change the delay needed depending on the command sent to the EZO Class EC Circuit.

char *ec;   //char pointer used in string parsing.
char *tds;  //char pointer used in string parsing.
char *sal;  //char pointer used in string parsing.
char *sg;   //char pointer used in string parsing.

float ec_float;   //float var used to hold the float value of the conductivity.
float tds_float;  //float var used to hold the float value of the TDS.
float sal_float;  //float var used to hold the float value of the salinity.
float sg_float;   //float var used to hold the float value of the specific gravity.




////Definições relacionadas com a bateria

// Set serial for debug console (to Serial Monitor, default speed 115200)
#define SerialMon Serial
// Set serial for AT commands (to SIM800 module)
#define SerialAT Serial1

/*#define IP5306_ADDR 0x75
#define IP5306_REG_SYS_CTL0 0x00
#define IP5306_REG_SYS_CTL1 0x01*/

#define TINY_GSM_MODEM_SIM800

// I2C for SIM800 (to keep it running when powered from battery)
//TwoWire I2CPower = TwoWire(0);

//Temperature sensor properties
// GPIO where the DS18B20 is connected to
const int oneWireBus = 4;
// Setup a oneWire instance to communicate with any OneWire devices
OneWire oneWire(oneWireBus);

// Pass our oneWire reference to Dallas Temperature sensor
DallasTemperature sensors(&oneWire);

//Water level sensor properties

#define ANALOG_PIN 32
#define RANGE 5000         // Depth measuring range 5000mm (for water)
#define VREF 3300          // 1100 mV for ESP32 5000 // ADC's reference voltage on your Arduino,typical value:5000mV
#define CURRENT_INIT 2.80  // Current @ 0mm (uint: mA) was 4.00
#define DENSITY_WATER 1    // Pure water density normalized to 1
#define PRINT_INTERVAL 1000



int16_t dataVoltage;
float dataCurrent;  //unit:mA
unsigned long timepoint_measure;



// WiFi connect timeout per AP. Increase when connecting takes longer.
const uint32_t connectTimeoutMs = 10000;

float pHreading;
char *fileName;


bool signupOK = false;
unsigned long sendDataPrevMillis = 0;


#define IP5306_ADDR 0x75
#define IP5306_REG_SYS_CTL0 0x00
#define I2C_SDA 21
#define I2C_SCL 22

#define uS_TO_S_FACTOR 1000000 /* Conversion factor for micro seconds to seconds */
#define TIME_TO_SLEEP 36000    //120//300      /* Time ESP32 will go to sleep (in seconds) */
int timeSleepSeconds;



void setup() {
  adc1_config_width(ADC_WIDTH_BIT_12);                  // Set ADC width to 12 bits
  adc1_config_channel_atten(ADC_PIN, ADC_ATTEN_DB_11);  // Set attenuation for the channel

  adc_chars = (esp_adc_cal_characteristics_t *)calloc(1, sizeof(esp_adc_cal_characteristics_t));  // Allocate memory for adc_chars
  esp_adc_cal_value_t val_type = esp_adc_cal_characterize(ADC_UNIT_1, ADC_ATTEN_DB_11, ADC_WIDTH_BIT_12, 1100, adc_chars);


  Wire.begin();
  analogReadResolution(12);
  analogSetWidth(12);

  Serial.begin(115200);
  spi.begin(SCK, MISO, MOSI, CS);

  // analogSetAttenuation(ADC_2_5db);
  //   analogSetSamples(1);

  // Restart SIM800 module, it takes quite some time
  // To skip it, call init() instead of restart()
 // SerialMon.println("Initializing modem...");
 // modem.restart();
  // use modem.init() if you don't need the complete restart



  // Configure the wake up source as timer wake up
  esp_sleep_enable_timer_wakeup(TIME_TO_SLEEP * uS_TO_S_FACTOR);

  sensors.begin();
  //ADC pin water level sensor
  pinMode(ANALOG_PIN, INPUT);

  //Calibração do pH
  delay(200);
  Serial.println(F("Use commands \"CAL,7\", \"CAL,4\", and \"CAL,10\" to calibrate the circuit to those respective values"));
  Serial.println(F("Use command \"CAL,CLEAR\" to clear the calibration"));
  if (pH.begin()) {
    Serial.println("Loaded EEPROM");
  }

  //variaveis cartao SD



  if (!SD.begin(CS, spi, 80000000)) {
    Serial.println("Card Mount Failed");
    return;
  }
  uint8_t cardType = SD.cardType();

  if (cardType == CARD_NONE) {
    Serial.println("No SD card attached");
    return;
  }

  Serial.print("SD Card Type: ");
  if (cardType == CARD_MMC) {
    Serial.println("MMC");
  } else if (cardType == CARD_SD) {
    Serial.println("SDSC");
  } else if (cardType == CARD_SDHC) {
    Serial.println("SDHC");
  } else {
    Serial.println("UNKNOWN");
  }

  uint64_t cardSize = SD.cardSize() / (1024 * 1024);
  Serial.printf("SD Card Size: %lluMB\n", cardSize);

  spi.end();


  // Set serial monitor debugging window baud rate to 115200
  SerialMon.begin(115200);

  // Start I2C communication
  I2CPower.begin(I2C_SDA, I2C_SCL, 400000);

  // Configure the wake up source as timer wake up
  esp_sleep_enable_timer_wakeup(TIME_TO_SLEEP * uS_TO_S_FACTOR);
}

void loop() {

  uint32_t adc_reading = 0;
  const uint8_t num_samples = 64;

  // Take multiple samples to reduce noise
  for (int i = 0; i < num_samples; i++) {
    adc_reading += adc1_get_raw(ADC_PIN);
  }
  adc_reading /= num_samples;

  // Convert ADC reading to voltage in mV
  uint32_t voltage = esp_adc_cal_raw_to_voltage(adc_reading, adc_chars);

  // Calculate the estimated USB voltage (in mV)
  float estimated_usb_voltage = voltage * 2.0;

  //Serial.println(v);

  String parameters[] = { "p", "c", "l", "t" };
  String units[] = { "Sorensen scale", "uS/cm", "wc", "°C" };
  String obs[] = { String(estimated_usb_voltage), "test", "test", "test" };

  float values[4];

  digitalWrite(MODEM_POWER_ON, LOW);
  delay(10);

  if (Serial.available() > 0) {
    user_bytes_received = Serial.readBytesUntil(13, user_data, sizeof(user_data));
  }

  if (user_bytes_received) {
    parse_cmd(user_data);
    user_bytes_received = 0;
    memset(user_data, 0, sizeof(user_data));
  }

  float temperatureC = getTemperature();


  pHreading = pH.read_ph();

  float  pHreadingV=pH.read_voltage();

  Serial.print("pH reading Voltage: ");
    Serial.print(pHreadingV);

  pHreading=nernestpHCompensationmV( temperatureC,  pHreadingV);


  values[0] = (pHreading);
  Serial.println("pHreading");
  Serial.println(pHreading);
    Serial.println("temperature");
  Serial.println(temperatureC);
  float condutct = getConductivity();
  values[1] = (condutct);
  float waterLevel = getLevel();
  values[2] = (waterLevel);
  values[3] = (temperatureC);


  
 // values[4] = (estimated_usb_voltage / 1000);

  // Set modem reset, enable, power pins
  pinMode(MODEM_PWKEY, OUTPUT);
  pinMode(MODEM_RST, OUTPUT);
  pinMode(MODEM_POWER_ON, OUTPUT);
  digitalWrite(MODEM_PWKEY, LOW);
  digitalWrite(MODEM_RST, HIGH);
  digitalWrite(MODEM_POWER_ON, HIGH);

  // Set GSM module baud rate and UART pins
  SerialAT.begin(115200, SERIAL_8N1, MODEM_RX, MODEM_TX);
  delay(3000);

  // Restart SIM800 module, it takes quite some time
  // To skip it, call init() instead of restart()
  SerialMon.println("Initializing modem...");
  modem.restart();

  // use modem.init() if you don't need the complete restart

  // Unlock your SIM card with a PIN if needed
  if (strlen(simPIN) && modem.getSimStatus() != 3) {
    modem.simUnlock(simPIN);
  }
  
  // Initialize the parameters
  Serial.println("Available parameters:");
  for (int i = 0; i < sizeof(units) / sizeof(units[0]); i++) {
    Serial.println(units[i]);
  }




postServer(apiKeyValue, parameters, values, units, obs);




delay(10000);

timeSleepSeconds = uS_TO_S_FACTOR * TIME_TO_SLEEP;

digitalWrite(MODEM_POWER_ON, LOW);
spi.end();
//esp_sleep_enable_timer_wakeup(3600000000);  //timer de uma hora


esp_sleep_enable_timer_wakeup(600000000);  //timer de 10 minutos
esp_deep_sleep_start();
}


float nernestpHCompensationmV(float temperature, float phmV) {
  float K = temperature + 273.15;
  double E = -0.0004 * phmV + 1.2660;//1.2560;
  Serial.println(E ); 

  const float E0 = + 0.22234;  // Standard electrode potential (V) at 25°C
  const float R = 8.314;     // Gas constant (J/(mol·K))

  const float n = 1;        // Number of electrons transferred
  const float F = 96485;    // Faraday's constant (C/mol)
  const float H_ref = 1.0;  // Reference concentration of hydrogen ions (mol/L)
  //
  //Serial.println("firstNernest");
  double firstNernest = (R * K) / (n * F);
  //Serial.println(firstNernest);
  double secondNernest = E - E0;
  // Serial.println(secondNernest);
  double thirdNernest = secondNernest / firstNernest;
  // Serial.println("thirdNernest");
  // Serial.println(thirdNernest);

  double e = exp(thirdNernest);

  // Calculate log base 10 using the natural logarithm result
  double result = log10(e);



  return result;
}

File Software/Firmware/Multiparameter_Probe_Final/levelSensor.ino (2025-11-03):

float getLevel() {
  float analogReading;
  float AntSum = 0;
  float Antavg = 0;
  float depth;
  //if (millis() - timepoint_measure > PRINT_INTERVAL) {
  //    timepoint_measure = millis();
  int Nmean=10000;
  //for (int l = 0; l < 2999; l++) {
    for (int l = 0; l < Nmean; l++) {

    analogReading=analogRead(ANALOG_PIN);
    dataVoltage = (analogReading) / 4095 * VREF;
   // Serial.println(ANALOG_PIN);
    dataCurrent = dataVoltage / 120.0; //Sense Resistor:120ohm
    //Serial.print("Data Current:"); Serial.println(dataCurrent);
    //Serial.println(dataCurrent);
     //Serial.println("Data current" );
    //Serial.println(dataCurrent);
    depth = (dataCurrent - CURRENT_INIT) * (RANGE / DENSITY_WATER / 16.0); //Calculate depth from current readings
    
    if (depth < 0)
    {
      depth = 0.0;
     // Serial.println("Depth 000");
    }
    AntSum += depth;
    //Serial.println(AntSum);
  }
  Antavg = AntSum / Nmean;
  if (Antavg < 0)
  {
    //Antavg = 0.0;
  }
  //Serial print results
  //Serial.print("depth:");
  //Serial.print(analogRead(ANALOG_PIN));
  // Serial.println(Antavg);
  // }
  //Serial.println("depth");
 //Serial.println(depth );
 //Serial.println("analog reading");
 //Serial.println(analogReading);
  return Antavg/10; //water column in cm
}

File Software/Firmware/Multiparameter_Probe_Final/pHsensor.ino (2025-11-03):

        

void parse_cmd(char* string) {                   
  strupr(string);                                
  if (strcmp(string, "CAL,7") == 0) {       
    pH.cal_mid();                                
    Serial.println("MID CALIBRATED");
  }
  else if (strcmp(string, "CAL,4") == 0) {            
    pH.cal_low();                                
    Serial.println("LOW CALIBRATED");
  }
  else if (strcmp(string, "CAL,10") == 0) {      
    pH.cal_high();                               
    Serial.println("HIGH CALIBRATED");
  }
  else if (strcmp(string, "CAL,CLEAR") == 0) { 
    pH.cal_clear();                              
    Serial.println("CALIBRATION CLEARED");
  }
}

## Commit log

2025-11-03 Board PCB
    Introducing Board PCB
    [Board V1.0-B_Cu.gbr, Board V1.0-B_Mask.gbr, Board V1.0-B_Paste.gbr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]
2025-11-03 ESP-32 Code
    Introduction of the multiparameter probe ESP32 - code
